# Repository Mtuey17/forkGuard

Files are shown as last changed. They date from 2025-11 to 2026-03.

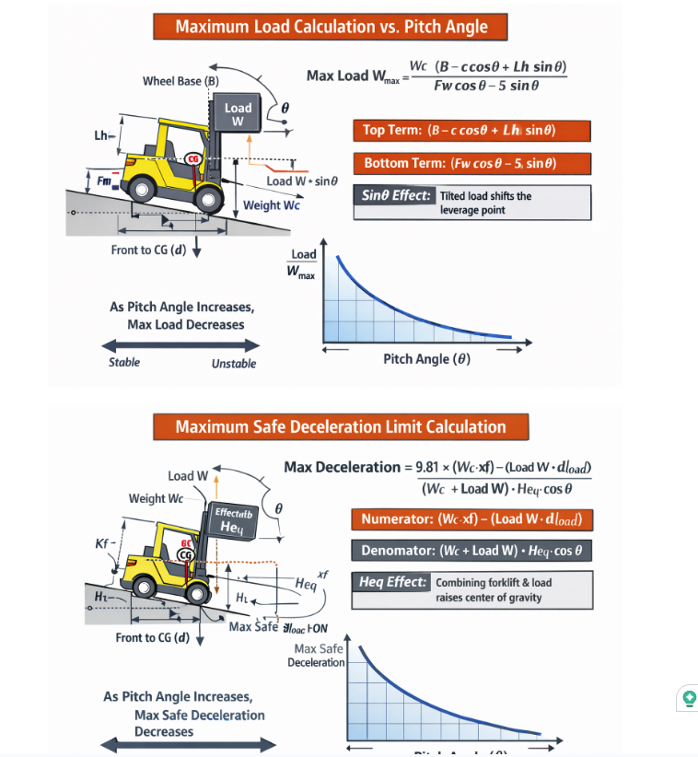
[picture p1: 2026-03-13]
wieghtGraphs.png

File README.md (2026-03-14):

# ForkGuard

ForkGuard is a capstone project focused on improving forklift safety through embedded systems, sensing, localization, and mechanical integration.

This repository contains the code, hardware-related files, schematics, and case design files used in the development of the ForkGuard prototype.

## Project Overview

The goal of ForkGuard is to build a prototype safety system for forklifts that can monitor important operating conditions and support safer vehicle use through embedded hardware and software.

The project includes work in several areas:
- embedded firmware development
- localization and positioning
- hardware integration
- case and mechanical design
- schematic development
- component-level testing and organization

## Repository Structure

```text
ForkGuard/
├── ArduinoFramework/   # Arduino-based code, tests, or support files
├── Case/               # Enclosure or mechanical case design files
├── components/         # Reusable components, modules, or project parts
├── EspIdfFramework/    # ESP-IDF-based firmware and embedded project files
├── Localization/       # Localization, positioning, or anchor-related code/files
├── orderLists/         # Parts lists, procurement notes, or ordering information
├── Schematics/         # Circuit schematics and electrical design files
└── README.md           # Project overview and documentation

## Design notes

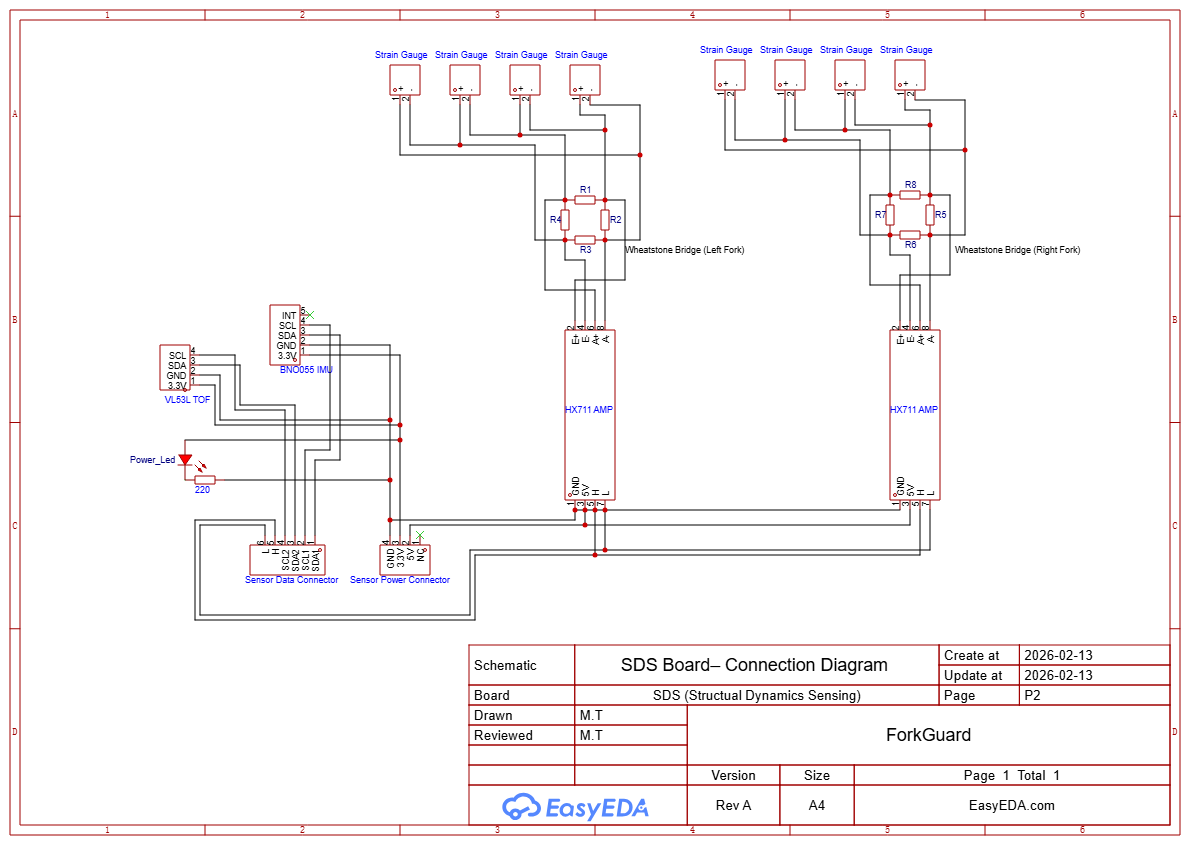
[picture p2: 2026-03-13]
Schematics/SDS-PNG.png

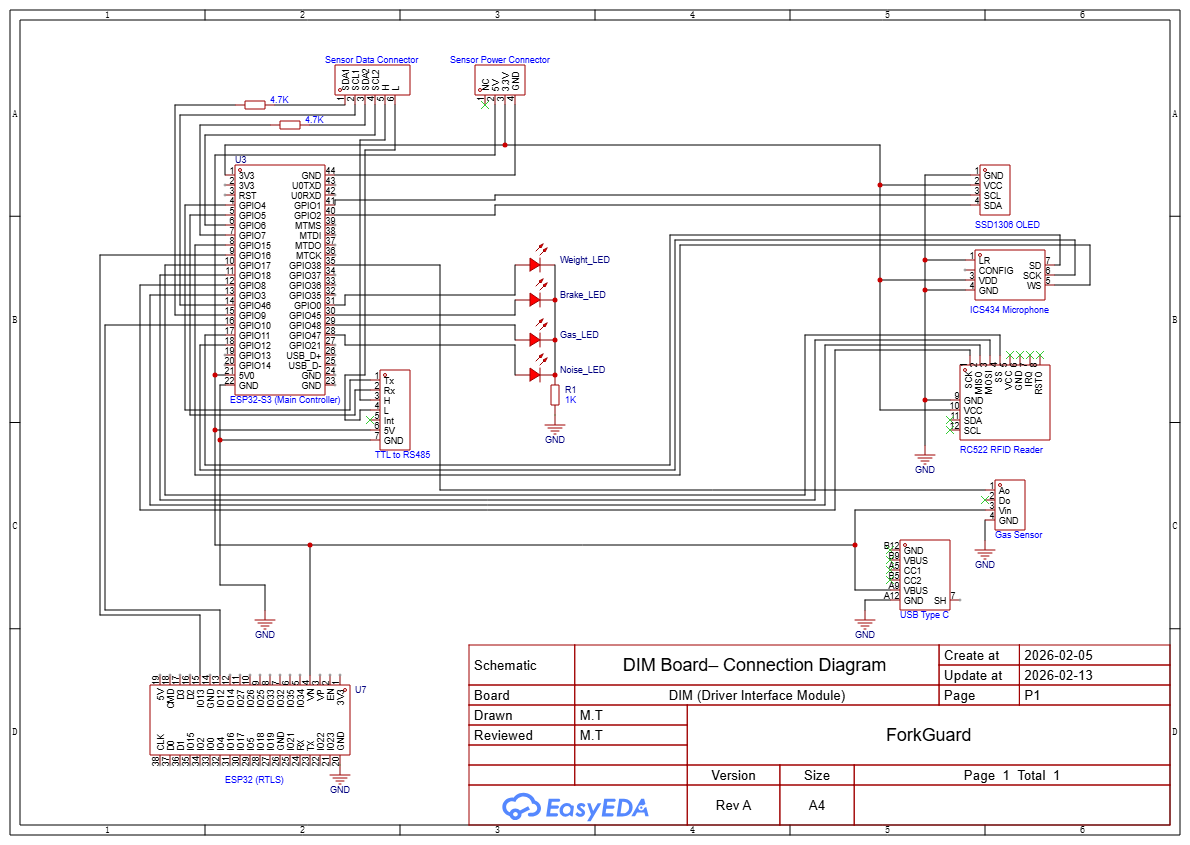
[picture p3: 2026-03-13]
Schematics/DIM-PNG.png

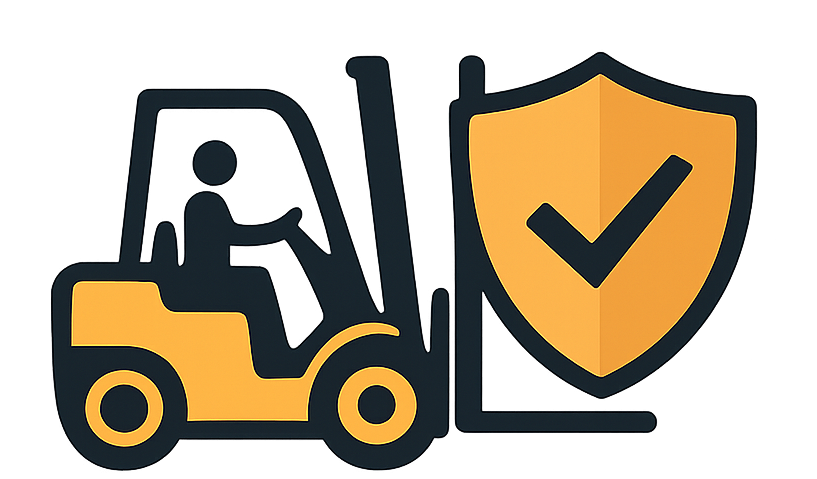
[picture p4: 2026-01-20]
forkGuardNoText.png

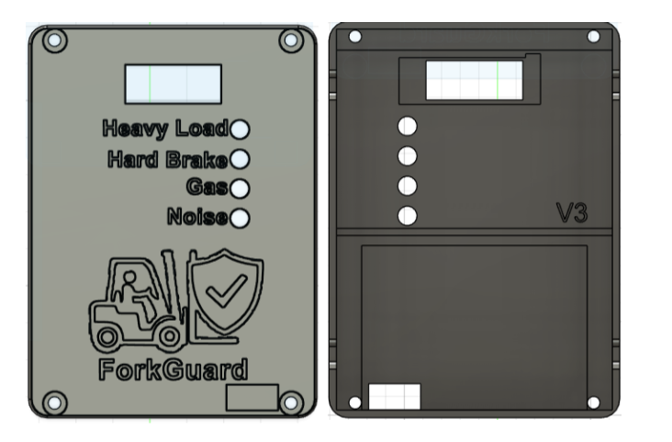
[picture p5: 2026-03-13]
Case/casePic.png

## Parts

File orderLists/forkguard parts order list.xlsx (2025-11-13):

 |  |  | Project Parts Request Form
Project Group Name and Number: |  |  | forkguard
Student Name, Number and Email Address: |  |  | matthew tuer | 8823727 | mtuer3727@conestogac.on.ca
Student Name, Number and Email Address: |  |  | Jackson Whynott | 8828711 | jwhynott8711@conestogac.on.ca
Student Name, Number and Email Address:
Student Name, Number and Email Address:
If the Parts are not returned in working condition or paid for by the end of the semester, grades and/or creditionals will not be issued
to the students until the account has been settled
Each group is entitled to $75 per student, which includes purchase price, taxes and shipping. You may not exceed this amount.
If you have purchases that exceeds the alloted amount, use must purchase this on your own to your own shipping address.
Make sure that parts are in-stock (available), or your part may not be delivered in time for your project!
Please only use the following distributors: |  |  | Digi-Key (http://www.digikey.ca/) | Newark (http://canada.newark.com/) | Sparkfun (https://www.sparkfun.com/)
 |  |  | Adafruit (https://www.adafruit.com/) | Robotshop (http://www.robotshop.com/ca/) | Elmwood (https://elmwoodelectronics.ca/)
Date | Quantity | Part Number | Link to Part Website | Description | Cost with taxes ($CAD) | Shipping Cost
2025-11-03 | 1 | B0DB1WK3CW | link (https://www.amazon.ca/SANXIXING-Development-Module-Internet-ESP32-S3-WROOM-1/dp/B0DB1WK3CW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) | microcontrollers | $29.98 | Free with prime
2025-11-03 | 1 | B0CXSC7S39 | link (https://www.amazon.ca/eMagTech-Female-Breakout-Electronic-Products/dp/B0CXSC7S39) | usb-c break out boards | $15.36 | Free with prime
2025-11-03 | 1 | B07PS4VCDD | link (https://www.amazon.ca/gp/product/B07PS4VCDD/ref=ox_sc_act_title_2?smid=A34CQKEVNF2MJX&psc=1) | protoboard kit | $28.24 | Free with prime
2025-11-03 | 1 | B0CKSDF6ZP | link (https://www.amazon.ca/Reciprocal-Hardware-Automatic-Control-Converter/dp/B0CKSDF6ZP) | TTL to RS485 converter | $11.85 | Free with prime
2025-11-03 | 1 | B09RH1QB6L | link (https://www.amazon.ca/GY-BNO055-Gyroscope-Internal-Stabilize-Communication/dp/B09RH1QB6L) | IMU | $34.00 | Free with prime
2025-11-03 | 1 | B0DX16YDYJ | link (https://www.amazon.ca/gp/product/B0DX16YDYJ/ref=ox_sc_act_title_2?smid=AUJJ6ROQ8ROWL&th=1) | mini Forklift for physics research and demo | $50.84 | Free with prime
2025-11-03 | 1 | B0C7L289Y2 | link (https://www.amazon.ca/LFRANK-Pieces-Display-Module-SSD1306/dp/B0C7L289Y2) | OLED displays | $17.50 | Free with prime
 |  |  | Total Cost (Quantity * Price With Tax + Shipping) : |  |  | $187.77

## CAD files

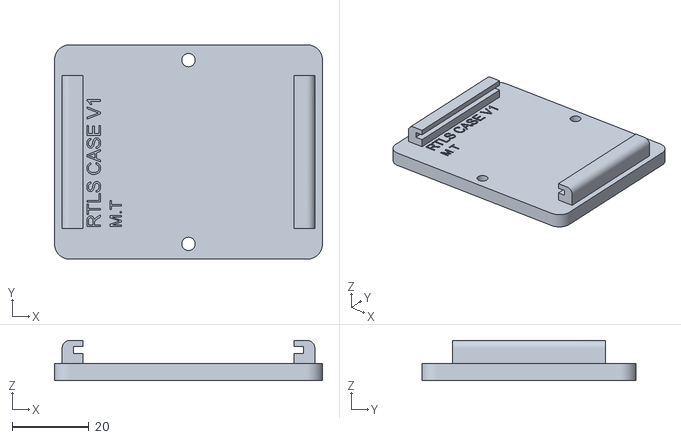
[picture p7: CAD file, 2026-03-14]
Case/RTLS_CASE_BOTTOM.stl
70.0 x 56.0 x 10.5

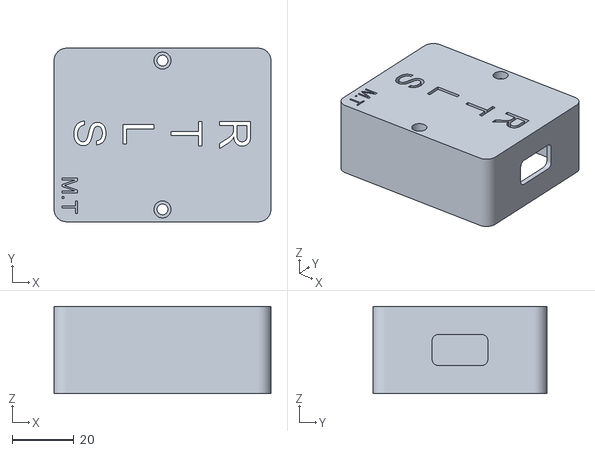
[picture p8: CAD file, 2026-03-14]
Case/RTLS_CASE_TOP.stl
70.0 x 56.0 x 28.2

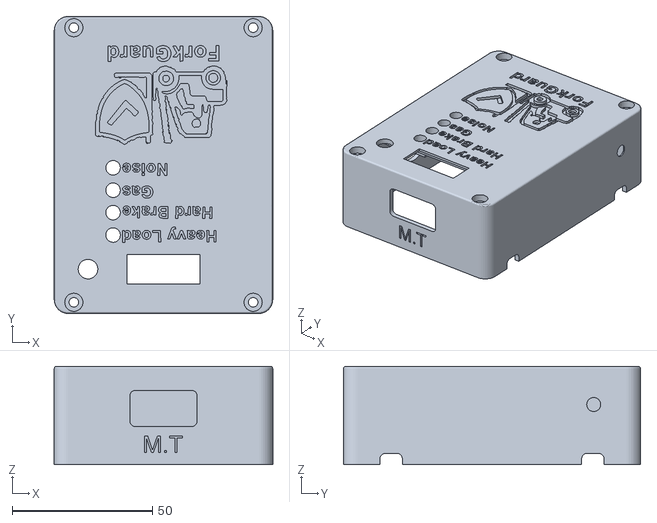
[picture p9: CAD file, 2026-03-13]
Case/DIM_TOP.stl
78.0 x 106.0 x 35.0

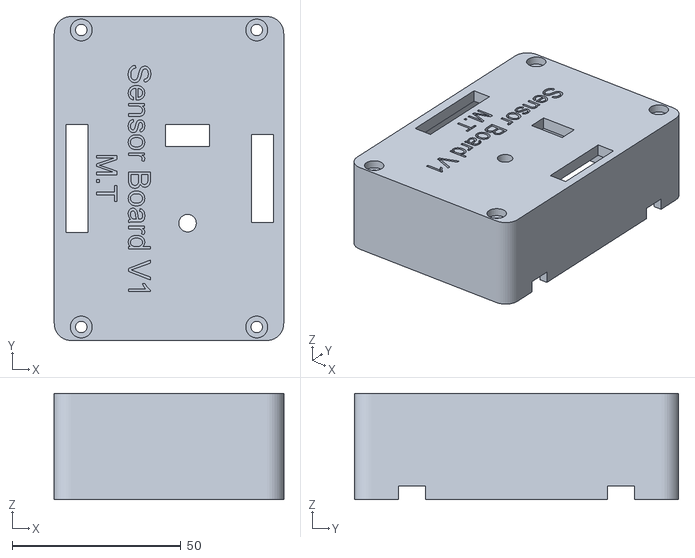
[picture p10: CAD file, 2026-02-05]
Case/sensorBoardTop.stl
68.0 x 96.0 x 31.5

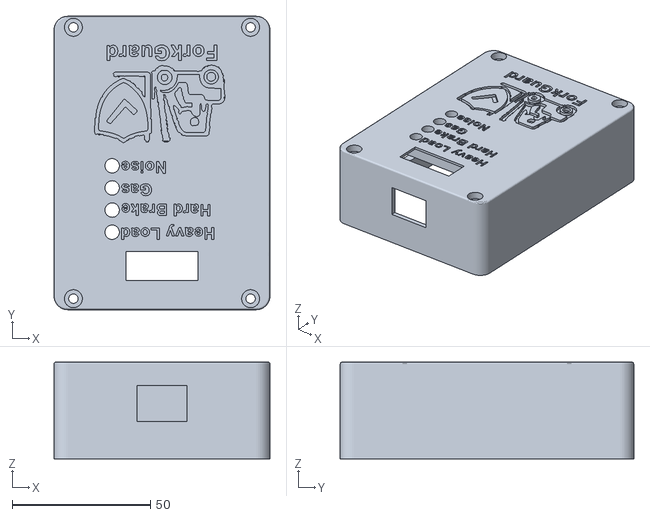
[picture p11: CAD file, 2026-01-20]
Case/caseTopV3_fixed.stl
78.0 x 106.0 x 35.0

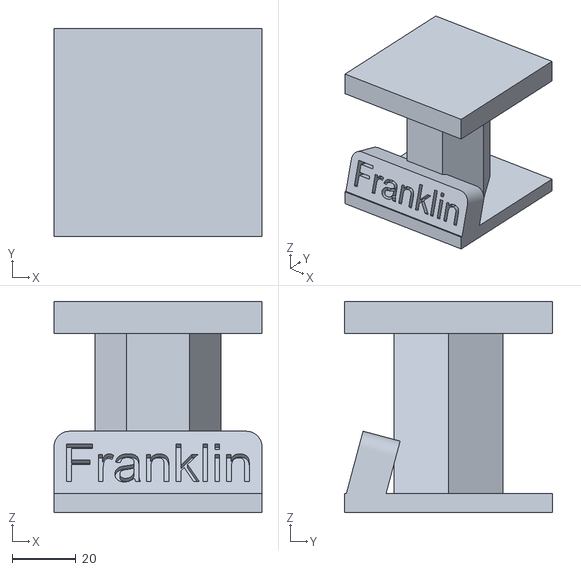
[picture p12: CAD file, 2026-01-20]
Case/franklinStatueV2.stl
65.0 x 65.0 x 66.0

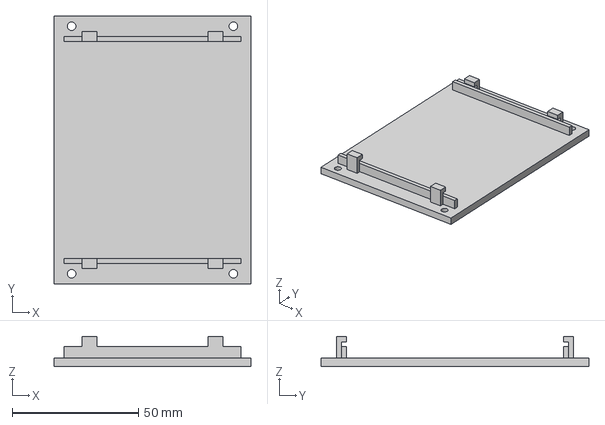
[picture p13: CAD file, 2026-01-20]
Case/slimBottomCase.3mf
78.0 x 106.0 x 12.0 mm

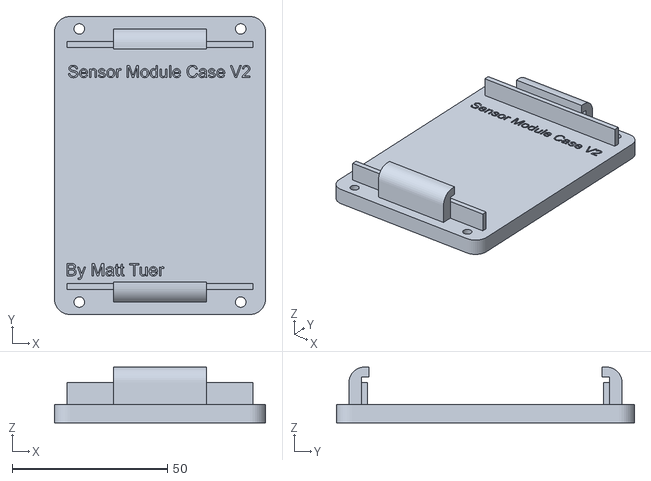
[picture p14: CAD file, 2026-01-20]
Case/sensorBoardBottomV2.stl
68.0 x 96.0 x 18.0

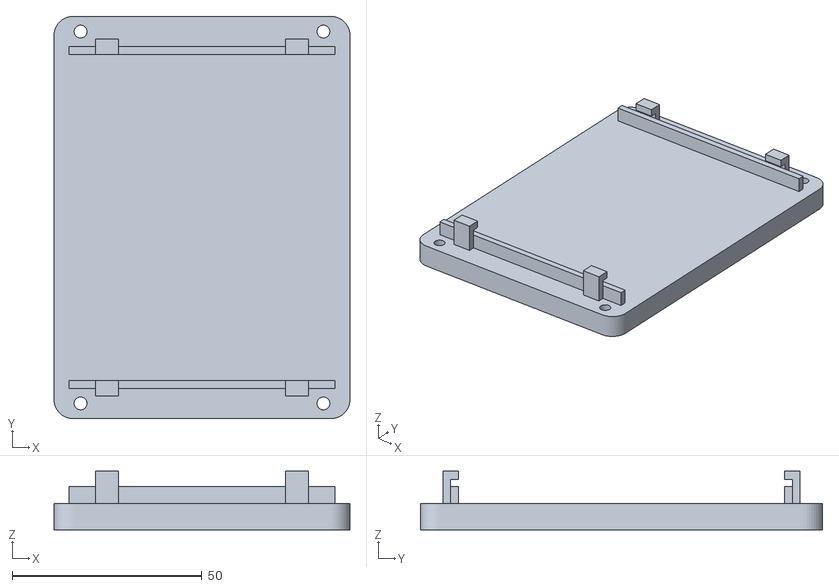
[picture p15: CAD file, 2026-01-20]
Case/caseBottomV2.stl
78.0 x 106.0 x 15.5

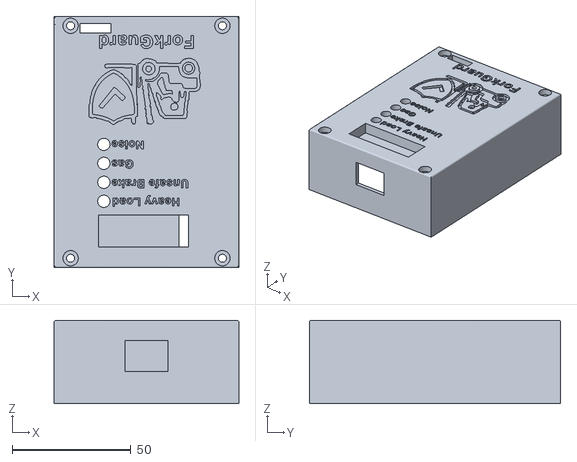
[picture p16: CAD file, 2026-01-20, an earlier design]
Case/oldFIles/caseTopV2_fixed.stl
78.0 x 106.0 x 35.0

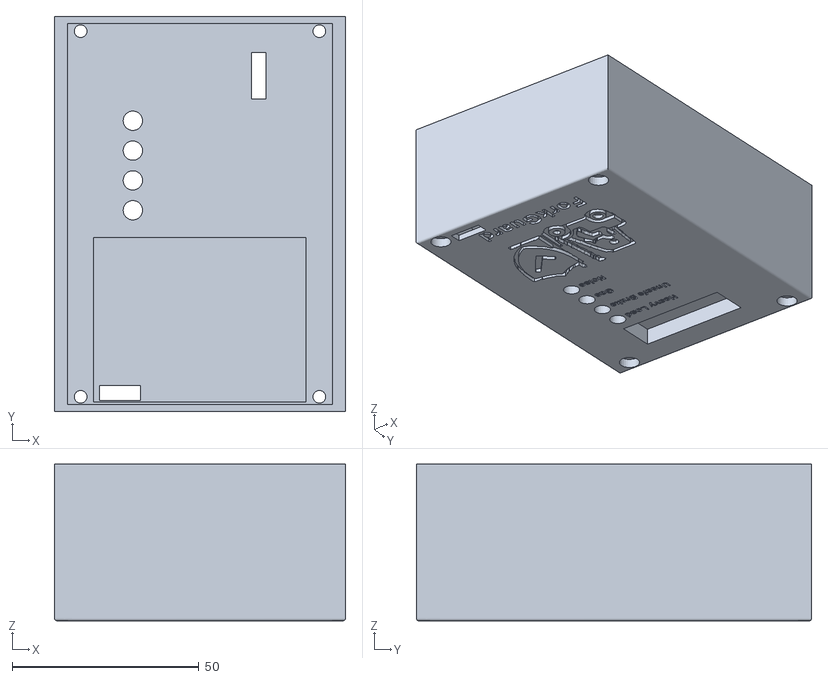
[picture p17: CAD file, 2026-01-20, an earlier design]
Case/oldFIles/caseTopFlipped.stl
78.0 x 106.0 x 42.0

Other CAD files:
Case/sensorBoardBottom.stl
Case/oldFIles/bottomCaseSlimSTL.stl
Case/oldFIles/caseTop.stl
Case/oldFIles/caseTopFlipped_fixed.stl
Case/oldFIles/caseTop_fixed.stl
Case/oldFIles/caseTopV3.stl
Case/oldFIles/caseTopV2.stl
Case/oldFIles/BottomCase.3mf

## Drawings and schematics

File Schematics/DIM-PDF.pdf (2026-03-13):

GND 22 GND 23 GND 24 USB_D- 25 USB_D+ 26 GPIO21 27 GPIO47 28 GPIO48 29 GPIO45 30 GPIO0 31 GPIO35 32 GPIO36 33 GPIO37 34 GPIO38 35 MTCK 36 MTDO 37 MTDI 38 MTMS 39 GPIO2 40 GPIO1 41 U0RXD 42 U0TXD 43 GND 44

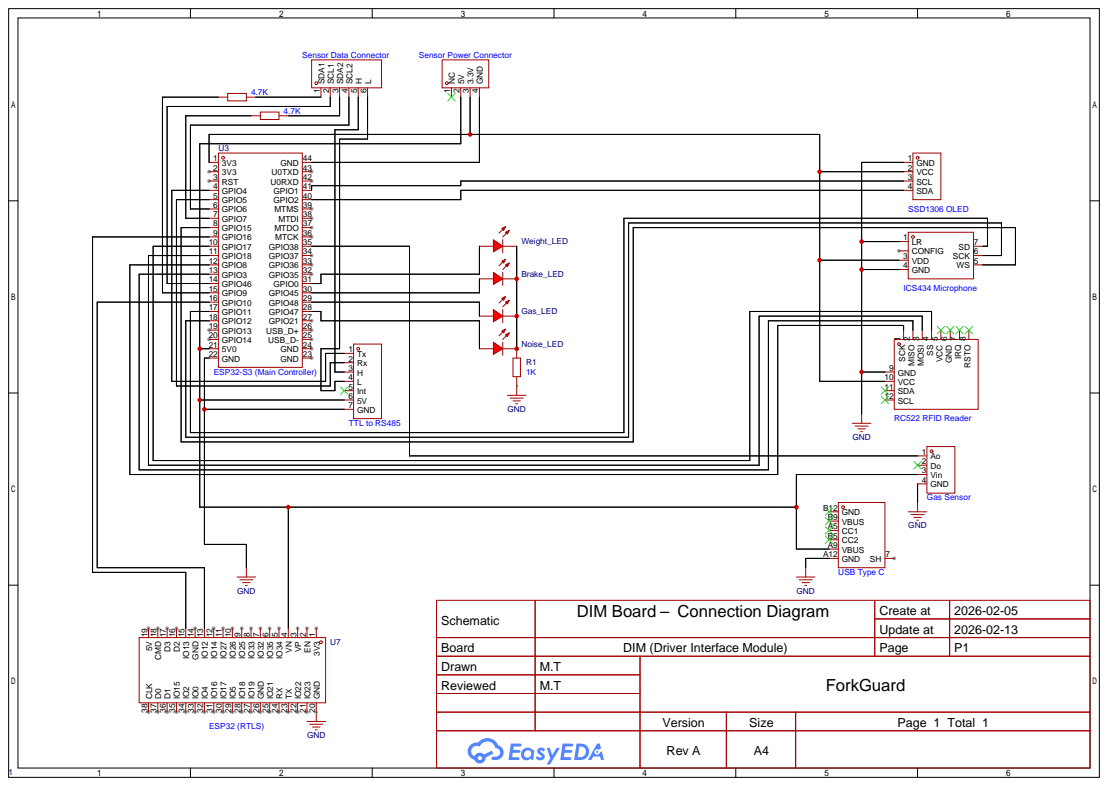
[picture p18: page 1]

Schematic | DIM Board Connection Diagram | Create at | 2026-02-05

Update at | 2026-02-13

Board | DIM (Driver Interface Module) | Page | P1
Drawn | M.T | ForkGuard
Reviewed | M.T

GND 20 IO23 21 IO22 22 TX 23 RX 24 IO21 25 GND 26 IO19 27 IO18 28 IO5 29 IO17 30 IO16 31 IO4 32 IO0 33 IO2 34 IO15 35 D1 36 D0 37 CLK 38

Version | Size | Page 1 Total 1
Rev A | A4

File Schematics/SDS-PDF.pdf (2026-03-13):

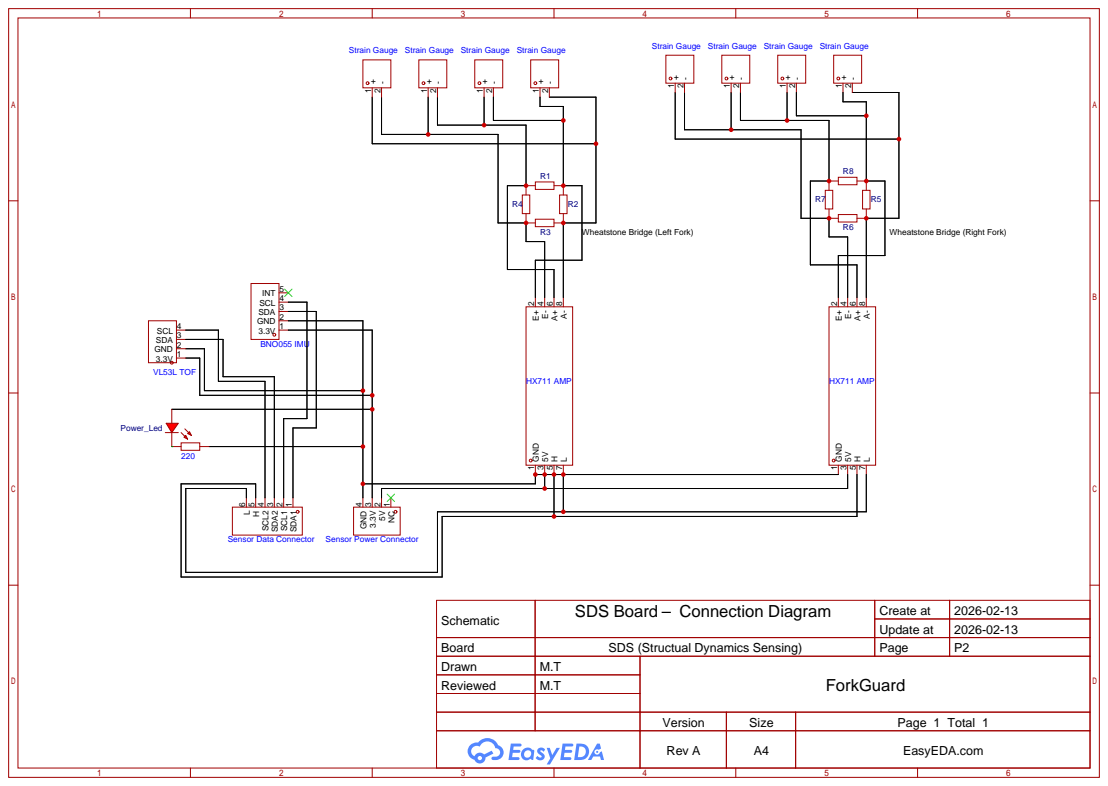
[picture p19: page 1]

Schematic | SDS Board Connection Diagram | Create at | 2026-02-13

Update at | 2026-02-13

Board | SDS (Structual Dynamics Sensing) | Page | P2
Drawn | M.T | ForkGuard
Reviewed | M.T

Version | Size | Page 1 Total 1
Rev A | A4 | EasyEDA.com

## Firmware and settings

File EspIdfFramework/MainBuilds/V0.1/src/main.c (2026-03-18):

/* Matthew Tuer 
november  16th, 2025
mtuer3727@conestogac.on.ca
matthewjtuer@gmail.com 


approx 1500 lines of code!!! (all .c files)


need to add interupt pin from RTLS
when RTLS sends data, it will drive a pin high
this pin will invoke an interupt where a RTLS_READY flag will be set 
when RTLS_READY flag is set, main loop will read from RTLS uart next run
RLTS_READY flag will then be reset 

pin 9 looks good for interupt pin
*/


#include "driver/gpio.h"
#include "driver/i2c_master.h"
#include "esp_log.h"
#include "freertos/FreeRTOS.h"
#include "freertos/task.h"
#include <ssd1306.h>
#include <bitmap_icon.h>
#include "string.h"
#include <stdio.h>
#include <math.h>
#include "driver/i2s_std.h"
#include "esp_timer.h"
#include "mfrc522.h"

//my custom made libraries 
#include "wirelessSetup.h"
#include "VL53L.h"
#include "IMU.h"
#include "liftDynamics.h"
#include "straingauge.h"
#include "OLED.h"
#include "RTLS.h"
#include "microphone.h"


volatile uint8_t UI_State=2;
volatile uint32_t lastPress=0;
volatile bool highLatch=false;
volatile bool previousLatchState=false;
volatile bool driverSelected;
volatile bool clearDisplay;
volatile uint32_t buttonPressStart = 0;
static void IRAM_ATTR button_isr_handler(void *arg)
{
    uint32_t currentTime=esp_timer_get_time()/1000;
    buttonPressStart=currentTime;
    if ((currentTime-lastPress)>200&&!highLatch&&driverSelected){     
    lastPress=currentTime;
    UI_State++;
    highLatch=true;
    if (UI_State>=4){UI_State=0;}
    if (UI_State==2){clearDisplay=true;}
    }
}

volatile bool RTLS_READY = false;
static void IRAM_ATTR rtls_isr_handler(void *arg)
{
RTLS_READY = true;
}

void updateLedSequence4(uint32_t *lastStepTime, uint8_t *ledState)
{
    const uint32_t stepPeriodMs = 150;
    uint32_t currentTime = esp_timer_get_time() / 1000;

    if ((currentTime - *lastStepTime) >= stepPeriodMs) {
        *lastStepTime = currentTime;

        // Turn all OFF
        gpio_set_level(GPIO_NUM_48, 0); // LED1
        gpio_set_level(GPIO_NUM_45, 0); // LED2
        gpio_set_level(GPIO_NUM_47, 0); // LED3
        gpio_set_level(GPIO_NUM_21, 0); // LED4

        // Turn ON one LED
        switch (*ledState) {
            case 0: gpio_set_level(GPIO_NUM_48, 1); break;
            case 1: gpio_set_level(GPIO_NUM_45, 1); break;
            case 2: gpio_set_level(GPIO_NUM_47, 1); break;
            case 3: gpio_set_level(GPIO_NUM_21, 1); break;
        }

        *ledState = (*ledState + 1) % 4;
    }
}

void app_main() {

    //------------DEFINITIONS, BUS INIT, WIFI/MQTT INIT------------
    #define WIFI_SSID "ForkGuardNet"
    #define WIFI_PASS "Guard1234"
    initWifi(WIFI_SSID,WIFI_PASS);
    MQTTHandler* MQTT=initMQTT();
    #define SDA1PIN 40
    #define SCL1PIN 41
    i2c_master_bus_config_t I2C_0_CONFIG = {
        .clk_source = I2C_CLK_SRC_DEFAULT,
        .i2c_port = I2C_NUM_0,
        .scl_io_num = SCL1PIN,
        .sda_io_num = SDA1PIN,
        .glitch_ignore_cnt = 7,
        .flags.enable_internal_pullup = true,
    };
    i2c_master_bus_handle_t bus_handle1;
    i2c_new_master_bus(&I2C_0_CONFIG, &bus_handle1);
    #define SDA2PIN 15
    #define SCL2PIN 16
    i2c_master_bus_config_t I2C_1_CONFIG = {
        .clk_source = I2C_CLK_SRC_DEFAULT,
        .i2c_port = I2C_NUM_1,
        .scl_io_num = SCL2PIN,
        .sda_io_num = SDA2PIN,
        .glitch_ignore_cnt = 7,
        .flags.enable_internal_pullup = true,
    };
    i2c_master_bus_handle_t bus_handle2;
    i2c_new_master_bus(&I2C_1_CONFIG, &bus_handle2);

    //I2S init for mic  
    #define PIN_SCK GPIO_NUM_17
    #define PIN_WS  GPIO_NUM_18
    #define PIN_SD  GPIO_NUM_8

    i2s_chan_config_t channel_config = I2S_CHANNEL_DEFAULT_CONFIG(I2S_NUM_AUTO, I2S_ROLE_MASTER);
    i2s_chan_handle_t I2S_Handle=NULL;
    i2s_new_channel(&channel_config, NULL, &I2S_Handle);
    i2s_std_config_t std_cfg = {
        .clk_cfg  = I2S_STD_CLK_DEFAULT_CONFIG(48000),
        .slot_cfg = I2S_STD_PHILIPS_SLOT_DEFAULT_CONFIG(I2S_DATA_BIT_WIDTH_32BIT,
                                                        I2S_SLOT_MODE_STEREO),
        .gpio_cfg = {
            .mclk = I2S_GPIO_UNUSED,
            .bclk = PIN_SCK,
            .ws   = PIN_WS,
            .dout = I2S_GPIO_UNUSED,
            .din  = PIN_SD,
            .invert_flags = { 0 },
        },
    };
    i2s_channel_init_std_mode(I2S_Handle, &std_cfg);
    i2s_channel_enable(I2S_Handle);    
    //------------DEFINITIONS, BUS INIT, WIFI/MQTT INIT------------

  
    //--------------------SENSOR INIT--------------------
    //Strain Amp setup
    #define RSTX 20
    #define RSRX 19
    #define RTLS_TX 5
    #define RTLS_RX 6
    HX711_t *leftForkSensor=HX711_init(UART_NUM_2,RSRX,RSTX,115200,2,2.06);//1.74626
    HX711_t *rightForkSensor=HX711_init(UART_NUM_2,RSRX,RSTX,115200,1,1.38);
    bool flipStrainRead=false; 
    bool reCalibrate=false;
    int lastWeightTime=0;
    IMU_t *IMU=initializeIMU(bus_handle1,0x29);//imu init 
    VL53L_t *TOF=initializeTOF(bus_handle2,0x29);// tof init 
    ForkLift *toyLift= initializeLift();//not a physical sensor, but struct where all forklift parameters are saved together 
    ssd1306_handle_t OLED=initializeOLED(bus_handle1);//OLED init (using same I2C bus as IMU)
    uint32_t lastUpdate=0;
    uint32_t pressTime=0;
    ssd1306_clear_display(OLED,false);
    ICS43434* microphone=InitICS(I2S_Handle);//micrphone init 
    mfrc522_init();//rfid init 

    
     RTLS_Instance *RTLS=RTLS_init(UART_NUM_1,RTLS_RX,RTLS_TX,115200);//rtls init 
    //--------------------SENSOR INIT--------------------
   

    //---------------------GPIO INIT---------------------
    #define GAS_SENSOR_PIN GPIO_NUM_35
    #define GAS_WARNING_LED GPIO_NUM_47
    #define NOISE_WARNING_LED GPIO_NUM_21
    #define RTLS_INT_PIN GPIO_NUM_9
    #define UI_SELECTION_BUTTON GPIO_NUM_14

    gpio_set_direction(UI_SELECTION_BUTTON,GPIO_MODE_INPUT);
    gpio_set_pull_mode(UI_SELECTION_BUTTON, GPIO_PULLUP_ONLY); 
    gpio_set_direction(GAS_SENSOR_PIN,GPIO_MODE_INPUT);
    gpio_set_direction(GAS_WARNING_LED,GPIO_MODE_OUTPUT);
    gpio_set_direction(NOISE_WARNING_LED,GPIO_MODE_OUTPUT);
    gpio_set_direction(GPIO_NUM_48,GPIO_MODE_OUTPUT);//weight warning LED
    gpio_set_direction(RTLS_INT_PIN,GPIO_MODE_INPUT);//int pin for RTLS uart 
    gpio_set_direction(GPIO_NUM_45,GPIO_MODE_OUTPUT);//brake warning LED
    gpio_set_pull_mode(RTLS_INT_PIN, GPIO_PULLUP_ONLY); 

    gpio_install_isr_service(ESP_INTR_FLAG_IRAM);
    gpio_set_intr_type(UI_SELECTION_BUTTON, GPIO_INTR_NEGEDGE);
    gpio_isr_handler_add(UI_SELECTION_BUTTON, button_isr_handler, NULL);
    gpio_set_intr_type(RTLS_INT_PIN, GPIO_INTR_POSEDGE);
    gpio_isr_handler_add(RTLS_INT_PIN, rtls_isr_handler, NULL);

    //---------------------GPIO INIT---------------------


    //---------------------MISC INIT---------------------

    //matching first byte of uid to a driver name (for UI)
    const char *driverNames[256] = {
    [(uint8_t)0x00] = "None",
    [(uint8_t)0xF9] = "Matthew",
    [(uint8_t)0x33] = "Bill .J",
    [(uint8_t)0xE3] = "Fred .M",
    };

    //---------------------MISC INIT---------------------

    ssd1306_display_bitmap(OLED,0,0,forklift_guard_icon_128x32,128,64,false);
    uint32_t startLogoTime=esp_timer_get_time()/1000;
    bool clearLatch=false;
    uint32_t lastLedStepTime = 0;
    uint8_t ledState = 0;
 
    while(1){
     


        uint32_t mainLoopStartTime=esp_timer_get_time()/1000;
        //----------------DATA AQUISITION----------------
        mfrc522_read_uid(toyLift->currentDriver);
        //flipping what strain gauge is being read every loop 
        if (flipStrainRead){HX711_updateWeight(leftForkSensor, 40);}
        else{HX711_updateWeight(rightForkSensor, 40);}
        flipStrainRead=!flipStrainRead;
        updateDistance(TOF); 
        updateAngles(IMU);
        updateAcceleration(IMU);
        toyLift->gas=gpio_get_level(GAS_SENSOR_PIN);
        checkMicLevel(microphone);
        toyLift->noise=microphone->dbHigh;
        if (RTLS_READY){
        UPDATE_LOCATION(RTLS,20);
        RTLS_READY=false;
        }
        if (gpio_get_level(UI_SELECTION_BUTTON)==1){highLatch=false; pressTime=0;}
        else{pressTime = (esp_timer_get_time()/1000) - buttonPressStart;}
        if (pressTime>=3000){//if button is held for 3 seconds, reset strain amps 
            leftForkSensor->offsetCheck=false;
            rightForkSensor->offsetCheck=false;
        }

        //----------------DATA AQUISITION----------------


        //---------------DATA MANIPULATION---------------
        toyLift->currentAccel=IMU->rawYAcceleration;
        if (toyLift->currentAccel<toyLift->hardestBraketoday){toyLift->hardestBraketoday=toyLift->currentAccel;}//seeing if this is max for today (for UI)
        toyLift->previousLoad=toyLift->currentLoad;
        toyLift->currentLoad=(leftForkSensor->kgWeight+rightForkSensor->kgWeight);
        if (toyLift->currentLoad>toyLift->highestWeightToday){toyLift->highestWeightToday=toyLift->currentLoad;}//seeing if this is max for today (for UI)

        if (toyLift->currentLoad>0.05){
        toyLift->loadBalance=100.0f*((leftForkSensor->kgWeight-rightForkSensor->kgWeight)/leftForkSensor->kgWeight+rightForkSensor->kgWeight);
        }else{toyLift->loadBalance=0.0f;}
        
        if (toyLift->currentLoad>0.150){reCalibrate=true; lastWeightTime=esp_timer_get_time()/1000;}

        int currentTime=esp_timer_get_time()/1000;
  
        if (reCalibrate&&toyLift->currentLoad<0.149&&(currentTime-lastWeightTime)>500){
            reCalibrate=false;
            leftForkSensor->offsetCheck=false;
            rightForkSensor->offsetCheck=false;
        }
            
       calculateDynamicLoad(toyLift,IMU->pitch,TOF->distance);//calculating max load at current pitch/load height
       calculateMaxDeaccel(toyLift,toyLift->currentLoad, TOF->distance, IMU->pitch);
       calculateSafetyScores(toyLift,toyLift->currentLoad,IMU->rawYAcceleration);
        //---------------DATA MANIPULATION---------------


        //------------OUTPUTS AND NETWORKING-------------
        //ssd1306_display_text(OLED,1,"Hello Billy J!",false);
        gpio_set_level(NOISE_WARNING_LED,toyLift->noise);
        gpio_set_level(GAS_WARNING_LED,!toyLift->gas);
      
        

         //when driver changes,make ui show driver page
         if ((esp_timer_get_time()/1000)-startLogoTime>3000){
         if (!clearLatch){ssd1306_clear_display(OLED,false);clearLatch=true;}
         if (memcmp(toyLift->currentDriver,toyLift->previousDriver,sizeof(toyLift->currentDriver)) != 0){UI_State=2;}
         if (clearDisplay){ssd1306_clear_display(OLED,false);clearDisplay=false;}
        switch ((UI_State))
        {
        case 0:
            showWeightInfo(OLED, &lastUpdate,toyLift);
            break;
        case 1:
            drawWeightChart(OLED,toyLift->currentLoad,toyLift->maxDynamicLoad);
            break;

        case 2:
            driverSelected=showDriver(OLED, &lastUpdate,driverNames,toyLift);
            break;

        default:
            drawBalanceChart(OLED,toyLift->loadBalance);
            break;
        }

    sendMQTT(MQTT,toyLift,RTLS);
    }else{updateLedSequence4(&lastLedStepTime, &ledState);}
            
    
            
        
        

        uint32_t mainLoopEndTime=esp_timer_get_time()/1000;
        uint16_t computeTime=mainLoopEndTime-mainLoopStartTime;
        //ESP_LOGI("main",":%d",RTLS->anchorId);
     

        

        //ESP_LOGI("main","left RAW: %ld KG: %f || right RAW:  %ld  KG: %f",leftForkSensor->Weight,leftForkSensor->kgWeight,rightForkSensor->Weight,rightForkSensor->kgWeight);
        //ESP_LOGI("main","noseDB: %f | HT: %d | CHT: %d",microphone->dbLevel,microphone->dbHigh,microphone->dbHighSustained);
        //ESP_LOGI("main","maxAccel: %f | currentAccel: %f",toyLift->maxAcceleration,toyLift->currentAccel);
        ESP_LOGI("main","pitch: %d | maxLoad: %f kg| currentLoad: %f kg| height: %dcm|GAS:%d|UID:%02X%02X%02X%02X|location:%d|ct:%d",IMU->pitch,toyLift->maxDynamicLoad,toyLift->currentLoad,TOF->distance,toyLift->gas,toyLift->currentDriver[0], toyLift->currentDriver[1], toyLift->currentDriver[2], toyLift->currentDriver[3],RTLS->anchorId,computeTime);


       
       /*
        if (toyLift->currentLoad>0.9f){
             break;
        }*/
        //------------OUTPUTS AND NETWORKING-------------
        //2.669600 
        //2.653740
        //2.648900

        vTaskDelay(pdMS_TO_TICKS(40));
    }
}

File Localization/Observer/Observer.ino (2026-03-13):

/* Matthew Tuer
   - Multi-scan BLE anchor selection (stable)
   - Per-scan de-dupe (use strongest RSSI sample per anchor per scan)
   - EMA smoothing across scans (more stable than simple average)
   - Serial monitor: debug
   - AnchorUart (UART2): ONLY closest anchor name (or "NONE")
   - INT pin pulses HIGH whenever UART data is sent
*/

#include <Arduino.h>
#include <BLEDevice.h>
#include <BLEScan.h>
#include <BLEAdvertisedDevice.h>

BLEScan* pBLEScan;

// ---------------------------
// CONFIG
// ---------------------------
static const int   SCAN_TIME_SECONDS = 5;
static const int   SCANS_PER_REPORT  = 2;
static const int   MAX_DEVICES       = 20;
static const int   MIN_REQUIRED_SEEN = 2;
static const float EMA_ALPHA         = 0.45f;
static const bool  USE_ACTIVE_SCAN   = true;

// ---------------------------
// SECOND UART (name-only output)
// ---------------------------
HardwareSerial AnchorUart(2);
static const int ANCHOR_UART_TX = 12;
static const int ANCHOR_UART_RX = 13;
static const uint32_t ANCHOR_UART_BAUD = 115200;

// ---------------------------
// UART INTERRUPT PIN
// ---------------------------
static const int UART_INT_PIN = 15;              // choose any free GPIO
static const uint32_t UART_INT_PULSE_MS = 10;    // pulse width

// ---------------------------
// Anchor tracking (persistent during window)
// ---------------------------
String anchorNames[MAX_DEVICES];
String anchorAddrs[MAX_DEVICES];
float  anchorEMA[MAX_DEVICES];
int    anchorSeenScans[MAX_DEVICES];
int    anchorCount = 0;

int scanCount = 0;

int findAnchorIndexByAddr(const String& addr) {
  for (int i = 0; i < anchorCount; i++) {
    if (anchorAddrs[i] == addr) return i;
  }
  return -1;
}

void resetAnchorsWindow() {
  for (int i = 0; i < anchorCount; i++) {
    anchorNames[i] = "";
    anchorAddrs[i] = "";
    anchorEMA[i] = -9999.0f;
    anchorSeenScans[i] = 0;
  }
  anchorCount = 0;
  scanCount = 0;
}

void sendAnchorMessage(const String& msg) {
  digitalWrite(UART_INT_PIN, HIGH);
  delay(1);
  AnchorUart.println(msg);
  delay(UART_INT_PULSE_MS);
  digitalWrite(UART_INT_PIN, LOW);
}

void doOneScanAccumulate() {
  Serial.println("Scanning...");

  BLEScanResults* results = pBLEScan->start(SCAN_TIME_SECONDS, false);

  String scanAddrs[MAX_DEVICES];
  String scanNames[MAX_DEVICES];
  int    scanBestRSSI[MAX_DEVICES];
  int    scanUniqueCount = 0;

  int total = results->getCount();

  for (int i = 0; i < total; i++) {
    BLEAdvertisedDevice dev = results->getDevice(i);

    if (!dev.haveName()) continue;

    String name = dev.getName().c_str();
    if (!name.startsWith("Anchor")) continue;

    String addr = dev.getAddress().toString().c_str();
    int rssi = dev.getRSSI();

    int scanIdx = -1;
    for (int j = 0; j < scanUniqueCount; j++) {
      if (scanAddrs[j] == addr) {
        scanIdx = j;
        break;
      }
    }

    if (scanIdx >= 0) {
      if (rssi > scanBestRSSI[scanIdx]) {
        scanBestRSSI[scanIdx] = rssi;
        scanNames[scanIdx] = name;
      }
    } else if (scanUniqueCount < MAX_DEVICES) {
      scanAddrs[scanUniqueCount] = addr;
      scanNames[scanUniqueCount] = name;
      scanBestRSSI[scanUniqueCount] = rssi;
      scanUniqueCount++;
    }
  }

  for (int k = 0; k < scanUniqueCount; k++) {
    const String& addr = scanAddrs[k];
    const String& name = scanNames[k];
    float sample = (float)scanBestRSSI[k];

    int idx = findAnchorIndexByAddr(addr);
    if (idx >= 0) {
      anchorEMA[idx] = EMA_ALPHA * sample + (1.0f - EMA_ALPHA) * anchorEMA[idx];
      anchorSeenScans[idx] += 1;
      anchorNames[idx] = name;
    } else if (anchorCount < MAX_DEVICES) {
      anchorAddrs[anchorCount] = addr;
      anchorNames[anchorCount] = name;
      anchorEMA[anchorCount] = sample;
      anchorSeenScans[anchorCount] = 1;
      anchorCount++;
    }
  }

  scanCount++;
  pBLEScan->clearResults();
}

void reportClosest() {
  if (anchorCount == 0) {
    Serial.println("NONE");
    sendAnchorMessage("NONE");
    return;
  }

  int bestIdx = -1;
  float bestScore = -9999.0f;

  Serial.print("Anchors (EMA): ");
  for (int i = 0; i < anchorCount; i++) {
    Serial.print(anchorNames[i]);
    Serial.print(" ema=");
    Serial.print(anchorEMA[i], 1);
    Serial.print(" seenScans=");
    Serial.print(anchorSeenScans[i]);
    Serial.print(" | ");

    if (anchorSeenScans[i] >= MIN_REQUIRED_SEEN && anchorEMA[i] > bestScore) {
      bestScore = anchorEMA[i];
      bestIdx = i;
    }
  }
  Serial.println();

  if (bestIdx < 0) {
    Serial.println("NONE");
    sendAnchorMessage("NONE");
    return;
  }

  Serial.println(anchorNames[bestIdx]);
  sendAnchorMessage(anchorNames[bestIdx]);
}

void setup() {
  Serial.begin(115200);
  delay(200);

  AnchorUart.begin(ANCHOR_UART_BAUD, SERIAL_8N1, ANCHOR_UART_RX, ANCHOR_UART_TX);

  pinMode(UART_INT_PIN, OUTPUT);
  digitalWrite(UART_INT_PIN, LOW);

  Serial.println("Initializing BLE scan...");

  BLEDevice::init("");
  pBLEScan = BLEDevice::getScan();

  pBLEScan->setActiveScan(USE_ACTIVE_SCAN);
  pBLEScan->setInterval(80);
  pBLEScan->setWindow(60);

  resetAnchorsWindow();
}

void loop() {
  doOneScanAccumulate();

  if (scanCount >= SCANS_PER_REPORT) {
    reportClosest();
    resetAnchorsWindow();
  }
}

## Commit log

2025-11-13 new code
    [forkguard parts order list.xlsx, mtuer.xlsx]
2026-02-05 added ble localization stack
    [Stocks.csv, customTag.cfg, data_x_x2_x3.csv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]
2026-03-13 rtls working and other stuff
    [DIM_TOP.stl]
